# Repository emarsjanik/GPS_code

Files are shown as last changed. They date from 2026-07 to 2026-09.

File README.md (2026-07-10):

# USGS GNSS Reference Station

Autonomous GNSS data logging, RINEX conversion, and GNSS-IR (interferometric reflectometry) processing built around a Unicore UM980 receiver.

For a full, zero-background operator's guide (installation, daily operation, troubleshooting), see [`docs/USER_MANUAL.docx`](docs/USER_MANUAL.docx). This README is the technical quick-reference.

## Data flow

```
UM980 receiver (USB serial)
        │
        ▼
receiver.py            Receiver.record_raw()
        │
        ▼
raw/*.um980             raw binary capture
        │
        ▼
rinex_processor.py      RinexProcessor.convert()  (wraps RTKLIB's convbin)
        │
        ▼
rinex/*.obs, *.nav      RINEX 3.05, with SNR observables
        │
        ▼
gnssrefl_processor.py   GnssIrProcessor.process()  (wraps gnssrefl: rinex2snr → gnssir)
        │
        ▼
products/refl_code/<year>/results/<station>/<doy>.txt   reflector heights
```

`pipeline.py` chains RINEX conversion and GNSS-IR processing for one file. `station_manager.py` chains recording, pipeline processing, and health checks for continuous, unattended operation.

## Requirements

- Ubuntu 20.04 (or compatible)
- Python 3.10+ (`gnssrefl` requires this; the system's default Python on Ubuntu 20.04 is 3.8 and cannot run it — see install notes below)
- [RTKLIB](https://github.com/rtklibexplorer/RTKLIB) (`convbin`), built from source
- [`gnssrefl`](https://github.com/kristinemlarson/gnssrefl) (installs via pip once on Python 3.10+)
- `pyserial`

## Quick start

```bash
git clone https://github.com/emarsjanik/GPS_code.git
cd GPS_code

python3.10 -m venv gnssrefl_venv
source gnssrefl_venv/bin/activate
pip install --upgrade pip
pip install pyserial gnssrefl

# station/resources/station.json needs station_id, lat/lon/height,
# receiver_port, gnssrefl_station_code, and gnssrefl_orbit_source
# (see Configuration below) before anything will work correctly.

python check_layout.py
python -m unittest discover -s tests -v
```

Full, from-scratch installation instructions (including building Python 3.10 and RTKLIB from source, confirmed working on Ubuntu 20.04) are in the user manual, Chapter 10.

## Module map

| Module | Responsibility |
|---|---|
| `config.py` | Loads/validates `station.json`; computes every project path relative to its own file location, not the CWD |
| `receiver.py` | `Receiver` class — all serial I/O with the UM980. Single low-level primitive (`read_message()`) handles both ASCII and binary (NovAtel/Unicore OEM7) framing. `record_raw()` supports chunked recording via `append=True` |
| `database.py` | `Database` class — SQLite persistence, 11 tables, WAL mode, self-upgrading schema |
| `rinex_processor.py` | `RinexProcessor` class — wraps `convbin`. **Requires `-os`** to include SNR observables; without it, output is silently useless for GNSS-IR (no error raised) |
| `gnssrefl_processor.py` | `GnssIrProcessor` class — wraps `gnssrefl` (`rinex2snr` → `gnssir`). See **gnssrefl integration notes** below — several non-obvious, confirmed quirks live here |
| `pipeline.py` | `Pipeline` class — chains RINEX conversion + GNSS-IR processing across whatever's new in `raw/`; archives raw files after successful processing |
| `station_manager.py` | `StationManager` class — top-level orchestrator for continuous operation. Records each UTC day in configurable chunks (default 3600s), runs the pipeline once a day completes, periodic health checks, graceful `SIGTERM`/`SIGINT` handling |
| `station.py` | One-shot dashboard/status check — connects, reports receiver + DB status, exits |
| `exceptions.py`, `version.py` | Shared exception types; version string |
| `start_station.sh`, `stop_station.sh` | Idempotent cron-based wrappers around `station_manager.py` — safe to call repeatedly (no-op if already running), used for autonomous start-on-boot + crash recovery in place of systemd |

All classes follow the same shape: `initialize()` (may raise on a real setup problem) → main working method (never raises for an ordinary operational failure — errors come back as a result object) → `status()` → `shutdown()`.

## gnssrefl integration notes

`gnssrefl_processor.py`'s complexity is almost entirely from confirmed, real quirks in `gnssrefl` 4.1.5 and `convbin`, not incidental design choices:

- **`rinex2snr()` decides RINEX 2.11 vs RINEX 3 purely by the length of the `station` argument** — 4 characters means "assume RINEX 2.11," 9 means "assume RINEX 3." Since `convbin` always outputs RINEX 3 here, `GnssIrProcessor` maintains two station codes: a 4-character one (used by `make_gnssir_input()` and `gnssir()`) and a 9-character one built from it plus a configurable monument number/country code (used only for `rinex2snr()` and the staged filename). Getting this wrong produces no error — just zero usable SNR data.
- **Staged filename convention**: `{STATION9}_R_{YYYY}{DOY}0000_01D_{RATE}S_MO.rnx`, staged under `$REFL_CODE/<year>/rinex/<4-char station>/`. The time segment is always `0000` regardless of the file's real start time.
- **Confirmed upstream bug**: `gnssrefl`'s file-discovery logic checks the current working directory for a same-named file *before* the properly staged directory, and reuses it forever if found — never refreshed. `_stage_rinex_file()` deletes any same-named file from the CWD before staging, specifically to prevent this.
- **Confirmed upstream bug**: `gps.checkEGM()` crashes with `TypeError` the first time `$REFL_CODE/Files` doesn't exist (malformed `subprocess.call()` argument). Worked around by creating that directory proactively in `initialize()`.
- **Reflector height / quality score parsing** is confirmed against a real results file's own header (`% year, doy, RH, sat, UTCtime, ...`): column 3 is RH (meters), column 14 is PkNoise. Reported as the mean across all parseable rows.
- **`soil_moisture`/`snow_depth` are always `None`** — these require separate, later `gnssrefl` modules operating on multi-day history, out of scope for a single day's `gnssir` run.
- Default orbit fetching (multi-GNSS SP3) failed in testing against CDDIS (likely requires an EarthData Login account, and/or same-day rapid products not yet published). Set `"gnssrefl_orbit_source": "nav"` in `station.json` to use broadcast GPS-only ephemeris instead — still requires a small internet download (SOPAC), not fully offline.

## Configuration (`station/resources/station.json`)

| Field | Purpose |
|---|---|
| `station_id`, `latitude`, `longitude`, `height` | Station identity and coordinates |
| `receiver_port`, `receiver_baud`, `receiver_timeout` | Serial connection to the UM980 |
| `rinex_version` | Passed to `convbin`; this project always uses `3.05` |
| `gnssrefl_station_code` | 4-character station code (see integration notes above) |
| `gnssrefl_monument_number`, `gnssrefl_country_code` | Used to build the 9-character RINEX 3 station code |
| `gnssrefl_orbit_source` | `"nav"` for offline-friendly broadcast ephemeris; unset for default multi-GNSS SP3 |
| `gnssrefl_sample_rate` | Recording sample rate in seconds; must match the real `LOG ... ONTIME` interval |
| `record_raw_chunk_seconds` | `StationManager` recording chunk size; 3600 (1h) default, 600 (10min) recommended for cron/systemd-managed deployments so stop/restart stay responsive |
| `manager_retry_delay_seconds`, `health_check_interval_seconds` | `StationManager` tuning |

## Running

```bash
# Autonomous (recommended) — cron-managed, survives crashes and reboots
~/GNSS/v4.1/station/start_station.sh    # idempotent; safe to call repeatedly
~/GNSS/v4.1/station/stop_station.sh     # graceful — waits for the current chunk to finish

# Direct (foreground, blocks)
python3 station_manager.py

# One-shot status check
python3 station.py
```

Crontab (used instead of systemd by choice — see commit history for the reasoning):

```
@reboot /home/argus_user/GNSS/v4.1/station/start_station.sh
*/5 * * * * /home/argus_user/GNSS/v4.1/station/start_station.sh
```

## Testing

```bash
python -m unittest discover -s tests -v
```

163 tests as of this writing, covering every module above with fake `Receiver`/`gnssrefl`/`Pipeline` stand-ins — no real hardware or `gnssrefl` install required to run the suite. All fakes are installed via `sys.modules` injection rather than mocking library internals, so the real integration code paths are exercised, not bypassed.

```bash
python check_layout.py
```

Verifies every expected file is present and non-empty/non-stub — useful after a fresh clone or file transfer.

## Directory outputs

| Path | Contents |
|---|---|
| `raw/` | Raw UM980 binary captures |
| `rinex/` | RINEX `.obs`/`.nav` files |
| `products/refl_code/` | `gnssrefl`'s entire working directory (`$REFL_CODE`) — analysis strategy JSON, staged RINEX, SNR files, results, logs |
| `database/` | `station.db` (SQLite) |
| `logs/` | `database.log`, and (cron setup) `station_manager.pid`/`station_manager.out` |
| `archive/` | Raw files moved here after successful processing |

None of the above are tracked in git (see `.gitignore`) — they're all generated data, along with `gnssrefl_venv/`.

## Hardware

- NUC (Ubuntu 20.04.6 LTS), shared with an unrelated I2R I2RGUS coastal camera system on the same machine
- ArduSimple SimpleRTK3B Budget receiver board (Unicore UM980 chip) — BeiDou/Galileo/GLONASS/GPS/NavIC/QZSS/SBAS
- ArduSimple budget tripleband GNSS antenna — 5 dBi, built-in LNA, IP66

Full specifications: user manual, Chapter 2.

## Known open items

- RINEX/product retention policy in `pipeline.py` is unimplemented — currently nothing prunes `rinex/`, `products/`, or `archive/` over time
- `convbin` build source lives at `~/software/RTKLIB/` on the deployed station (not in this repo) — see user manual Chapter 10 for build steps
- BeiDou/Galileo ephemeris logging works but hasn't been observed within short test windows; needs a longer recording to confirm reliably

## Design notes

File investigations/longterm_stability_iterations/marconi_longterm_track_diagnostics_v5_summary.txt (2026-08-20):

MARCONI LONG-TERM GNSS-R / TIDE TRACK DIAGNOSTICS V5
==============================================================================================================
Primary tide model: EOT20_heightm
Station H_ortho: 18.665 m
Azimuth cluster tolerance: 3.0 deg

GOOD TRACK CRITERIA
--------------------------------------------------------------------------------------------------------------
Minimum observations: 14
Minimum unique days: 14
Minimum tide correlation r: 0.90
Slope range: 0.85 to 1.15
Maximum unit-slope RMS: 30.0 cm
Maximum azimuth SD: 1.00 deg

IMPORTANT
--------------------------------------------------------------------------------------------------------------
The +0.242 m datum offset is diagnostic only.
It is NOT used to select GOOD tracks.
Failure reasons are reported independently for every criterion.

GPS L1 observations matched to tide: 536
Clustered tracks: 28
GOOD tracks: 19

GOOD TRACKS
--------------------------------------------------------------------------------------------------------------
 1. SAT= 29 rise= 1 N= 25 days=25 Az= 113.00±0.04 r=+0.9745 slope=+0.9519 unitRMS=16.49cm
 2. SAT=  9 rise=-1 N= 20 days=20 Az=  35.01±0.01 r=+0.9775 slope=+1.0310 unitRMS=14.85cm
 3. SAT= 25 rise=-1 N= 18 days=18 Az=  47.61±0.02 r=+0.9761 slope=+0.8979 unitRMS=18.53cm
 4. SAT=  9 rise= 1 N= 20 days=20 Az= 124.45±0.05 r=+0.9742 slope=+1.0215 unitRMS=14.03cm
 5. SAT= 29 rise=-1 N= 16 days=16 Az=  33.33±0.02 r=+0.9721 slope=+0.9976 unitRMS=18.52cm
 6. SAT=  4 rise= 1 N= 20 days=20 Az=  96.33±0.02 r=+0.9367 slope=+0.9034 unitRMS=20.66cm
 7. SAT=  8 rise=-1 N= 20 days=20 Az=  83.42±0.15 r=+0.9596 slope=+1.0171 unitRMS=23.95cm
 8. SAT=  4 rise=-1 N= 18 days=18 Az=  30.52±0.01 r=+0.9629 slope=+0.9156 unitRMS=18.89cm
 9. SAT= 27 rise=-1 N= 18 days=18 Az=  63.42±0.01 r=+0.9644 slope=+0.9208 unitRMS=22.00cm
10. SAT= 30 rise= 1 N= 21 days=21 Az= 102.97±0.02 r=+0.9463 slope=+0.9421 unitRMS=20.96cm
11. SAT= 28 rise=-1 N= 18 days=18 Az= 114.26±0.09 r=+0.9561 slope=+0.9674 unitRMS=21.36cm
12. SAT= 20 rise=-1 N= 22 days=22 Az=  69.89±0.11 r=+0.9376 slope=+0.9273 unitRMS=24.02cm
13. SAT=  2 rise=-1 N= 20 days=20 Az=  52.88±0.06 r=+0.9321 slope=+0.9867 unitRMS=26.57cm
14. SAT= 12 rise=-1 N= 23 days=23 Az=  37.54±0.01 r=+0.9583 slope=+0.8733 unitRMS=21.48cm
15. SAT=  6 rise=-1 N= 21 days=21 Az= 114.72±0.14 r=+0.9345 slope=+0.9793 unitRMS=23.69cm
16. SAT= 21 rise=-1 N= 21 days=21 Az=  92.86±0.18 r=+0.9089 slope=+0.9246 unitRMS=26.55cm
17. SAT=  5 rise=-1 N= 19 days=19 Az= 117.30±0.21 r=+0.9419 slope=+0.8847 unitRMS=23.18cm
18. SAT= 16 rise=-1 N= 18 days=18 Az=  96.47±0.08 r=+0.9310 slope=+0.8633 unitRMS=27.23cm
19. SAT= 30 rise=-1 N= 19 days=19 Az=  33.75±0.01 r=+0.9217 slope=+0.9210 unitRMS=26.03cm

ALL TRACKS — RANKED BY LONG-TERM SCORE
--------------------------------------------------------------------------------------------------------------
 1. SAT= 29 rise= 1 N= 25 days=25 Az= 113.00±0.04 r=+0.9745 slope=+0.9519 unitRMS=16.49cm FAIL=PASS score=0.824
 2. SAT=  9 rise=-1 N= 20 days=20 Az=  35.01±0.01 r=+0.9775 slope=+1.0310 unitRMS=14.85cm FAIL=PASS score=0.811
 3. SAT= 25 rise=-1 N= 18 days=18 Az=  47.61±0.02 r=+0.9761 slope=+0.8979 unitRMS=18.53cm FAIL=PASS score=0.800
 4. SAT=  9 rise= 1 N= 20 days=20 Az= 124.45±0.05 r=+0.9742 slope=+1.0215 unitRMS=14.03cm FAIL=PASS score=0.798
 5. SAT= 29 rise=-1 N= 16 days=16 Az=  33.33±0.02 r=+0.9721 slope=+0.9976 unitRMS=18.52cm FAIL=PASS score=0.788
 6. SAT=  4 rise= 1 N= 20 days=20 Az=  96.33±0.02 r=+0.9367 slope=+0.9034 unitRMS=20.66cm FAIL=PASS score=0.786
 7. SAT=  8 rise=-1 N= 20 days=20 Az=  83.42±0.15 r=+0.9596 slope=+1.0171 unitRMS=23.95cm FAIL=PASS score=0.781
 8. SAT=  4 rise=-1 N= 18 days=18 Az=  30.52±0.01 r=+0.9629 slope=+0.9156 unitRMS=18.89cm FAIL=PASS score=0.781
 9. SAT= 27 rise=-1 N= 18 days=18 Az=  63.42±0.01 r=+0.9644 slope=+0.9208 unitRMS=22.00cm FAIL=PASS score=0.780
10. SAT= 30 rise= 1 N= 21 days=21 Az= 102.97±0.02 r=+0.9463 slope=+0.9421 unitRMS=20.96cm FAIL=PASS score=0.770
11. SAT= 28 rise=-1 N= 18 days=18 Az= 114.26±0.09 r=+0.9561 slope=+0.9674 unitRMS=21.36cm FAIL=PASS score=0.768
12. SAT= 20 rise=-1 N= 22 days=22 Az=  69.89±0.11 r=+0.9376 slope=+0.9273 unitRMS=24.02cm FAIL=PASS score=0.767
13. SAT=  2 rise=-1 N= 20 days=20 Az=  52.88±0.06 r=+0.9321 slope=+0.9867 unitRMS=26.57cm FAIL=PASS score=0.761
14. SAT= 12 rise=-1 N= 23 days=23 Az=  37.54±0.01 r=+0.9583 slope=+0.8733 unitRMS=21.48cm FAIL=PASS score=0.754
15. SAT= 13 rise=-1 N= 13 days=13 Az=  38.84±0.07 r=+0.9684 slope=+0.8717 unitRMS=19.15cm FAIL=N,DAYS score=0.750
16. SAT=  6 rise=-1 N= 21 days=21 Az= 114.72±0.14 r=+0.9345 slope=+0.9793 unitRMS=23.69cm FAIL=PASS score=0.744
17. SAT=  1 rise=-1 N= 20 days=20 Az=  56.25±0.08 r=+0.8903 slope=+0.9349 unitRMS=29.04cm FAIL=R score=0.742
18. SAT= 21 rise=-1 N= 21 days=21 Az=  92.86±0.18 r=+0.9089 slope=+0.9246 unitRMS=26.55cm FAIL=PASS score=0.738
19. SAT=  5 rise=-1 N= 19 days=19 Az= 117.30±0.21 r=+0.9419 slope=+0.8847 unitRMS=23.18cm FAIL=PASS score=0.733
20. SAT= 26 rise=-1 N= 17 days=17 Az=  90.74±0.20 r=+0.8957 slope=+0.9088 unitRMS=29.37cm FAIL=R score=0.724
21. SAT= 16 rise=-1 N= 18 days=18 Az=  96.47±0.08 r=+0.9310 slope=+0.8633 unitRMS=27.23cm FAIL=PASS score=0.723
22. SAT= 15 rise=-1 N= 24 days=24 Az=  93.24±0.19 r=+0.8934 slope=+0.8980 unitRMS=30.68cm FAIL=R,RMS score=0.721
23. SAT= 24 rise=-1 N= 25 days=25 Az=  57.25±0.06 r=+0.9267 slope=+0.8372 unitRMS=25.05cm FAIL=SLOPE score=0.708
24. SAT= 30 rise=-1 N= 19 days=19 Az=  33.75±0.01 r=+0.9217 slope=+0.9210 unitRMS=26.03cm FAIL=PASS score=0.703
25. SAT= 12 rise= 1 N=  5 days= 5 Az= 133.23±0.06 r=+0.9777 slope=+0.6363 unitRMS=8.48cm FAIL=N,DAYS,SLOPE score=0.696
26. SAT=  3 rise=-1 N= 19 days=19 Az=  37.17±0.05 r=+0.9231 slope=+0.8107 unitRMS=23.24cm FAIL=SLOPE score=0.692
27. SAT= 31 rise=-1 N= 11 days=11 Az= 127.07±0.08 r=+0.9334 slope=+1.0884 unitRMS=21.15cm FAIL=N,DAYS score=0.670
28. SAT= 19 rise=-1 N= 14 days=14 Az= 148.96±0.13 r=+0.1945 slope=+0.0154 unitRMS=66.00cm FAIL=R,SLOPE,RMS score=0.231

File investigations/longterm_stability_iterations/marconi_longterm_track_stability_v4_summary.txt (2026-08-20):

MARCONI LONG-TERM GNSS-R / TIDE PIPELINE V4
============================================================================================

GNSS-IR configuration: ocean17_23_l1_e5_13
Primary tide model: EOT20_heightm
Diagnostic offset: +0.242 m

GOOD-track criteria:
  observations >= 14
  unique days   >= 14
  tide r        >= 0.9
  slope         = 0.85 to 1.15
  unit RMS      <= 30.0 cm
  azimuth SD    <= 1.0 deg
  +24.2 cm is NOT used to select good tracks.

Total clustered tracks: 34
GOOD tracks: 0

GOOD-TRACK POPULATION STATISTICS
--------------------------------------------------------------------------------------------
Mean bias                                   nan cm                  nan cm
Mean absolute deviation                     nan cm                  nan cm
Median absolute deviation                   nan cm                  nan cm
RMS                                         nan cm                  nan cm

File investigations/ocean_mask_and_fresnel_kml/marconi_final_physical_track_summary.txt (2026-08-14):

MARCONI FINAL PHYSICAL GNSS-R TRACK SCREEN
================================================================================================

Topobathy: 2021022FA_Marconi_topobathy_1m.tif
Primary tide: EOT20_heightm
H_ortho: 18.665 m
Datum transformation: +0.242 m

STATISTICAL SCREEN:
  N >= 10
  |median bias| <= 0.050 m
  RMS <= 0.200 m
  r >= 0.93

PHYSICAL SCREEN:
  adequate raster coverage >= 0.90
  9° water-dominant >= 0.80
  A-class 13° water >= 0.50

Statistically selected tracks: 4
Physically accepted A/B tracks: 2
Final observations: 29
Daily product days: 20

TRACK CLASSIFICATION
------------------------------------------------------------------------------------------------
PRN 29 RISING  Az= 113.01 N=23 r=+0.9765 RMS=16.5 cm bias=-3.2 cm C5=0.000 C9=0.450 C13=1.000 W5=nan W9=1.000 W13=0.350 C_INSUFFICIENT_RASTER_COVERAGE
PRN 13 SETTING Az=  38.84 N=12 r=+0.9719 RMS=19.5 cm bias=+4.0 cm C5=1.000 C9=1.000 C13=0.998 W5=1.000 W9=0.933 W13=0.058 B_WATER_DOMINANT_LOW_ANGLE
PRN  4 RISING  Az=  96.33 N=17 r=+0.9459 RMS=19.7 cm bias=+0.2 cm C5=0.668 C9=1.000 C13=1.000 W5=1.000 W9=1.000 W13=0.702 B_WATER_DOMINANT_LOW_ANGLE
PRN  9 RISING  Az= 124.46 N=17 r=+0.9759 RMS=13.7 cm bias=+2.1 cm C5=0.000 C9=0.000 C13=0.456 W5=nan W9=nan W13=0.000 C_INSUFFICIENT_RASTER_COVERAGE

FINAL WATER-LEVEL PRODUCT STATUS
------------------------------------------------------------------------------------------------
Only A/B tracks are included in the final combined product.
C tracks require a larger topobathy raster.
D/E tracks are not physically accepted under the current rules.

FINAL TRACKS:
  PRN 13 S Az=38.8° class=B_WATER_DOMINANT_LOW_ANGLE
  PRN 4 R Az=96.3° class=B_WATER_DOMINANT_LOW_ANGLE

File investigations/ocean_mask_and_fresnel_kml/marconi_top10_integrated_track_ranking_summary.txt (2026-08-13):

MARCONI TOP-10 INTEGRATED GNSS-R / FRESNEL / TOPOBATHY TEST
====================================================================================================
Top N: 10
Minimum repeated-track N: 3
Geometry elevations: [5.0, 9.0, 13.0]
DATUM_SHIFT_M: +0.00 m

CLASSIFICATION
A = strong ocean candidate: N>=4, |r|>=0.99,
    slope 0.85-1.15, unit RMS<=10 cm, wet13>=70%
B = probable ocean / mixed shoreline
C = tide-responsive but geometry not confirmed
D = weak or non-tidal

FINAL RANKING
----------------------------------------------------------------------------------------------------
 1. SAT= 26 N= 4 Az=90.93 r=+0.9966 slope=+0.9400 RMS=4.18cm wet13=0.750 class=A_STRONG_OCEAN_CANDIDATE score=0.861
 2. SAT=  1 N= 4 Az=56.33 r=+0.9817 slope=+0.7963 RMS=10.63cm wet13=0.793 class=B_PROBABLE_OCEAN_OR_MIXED_SHORELINE score=0.826
 3. SAT= 21 N= 4 Az=92.93 r=+0.9973 slope=+1.2293 RMS=7.31cm wet13=0.717 class=B_PROBABLE_OCEAN_OR_MIXED_SHORELINE score=0.811
 4. SAT= 24 N= 4 Az=57.28 r=+0.9591 slope=+0.6829 RMS=13.84cm wet13=0.797 class=C_TIDE_RESPONSIVE_GEOMETRY_UNCONFIRMED score=0.781
 5. SAT= 16 N= 4 Az=96.40 r=+0.9952 slope=+1.4264 RMS=11.48cm wet13=0.602 class=C_TIDE_RESPONSIVE_GEOMETRY_UNCONFIRMED score=0.765
 6. SAT=  2 N= 4 Az=52.82 r=+0.9633 slope=+0.6438 RMS=15.31cm wet13=0.664 class=C_TIDE_RESPONSIVE_GEOMETRY_UNCONFIRMED score=0.754
 7. SAT= 12 N= 3 Az=37.54 r=+0.9929 slope=+0.9896 RMS=4.45cm wet13=0.274 class=C_TIDE_RESPONSIVE_GEOMETRY_UNCONFIRMED score=0.690
 8. SAT= 28 N= 4 Az=114.33 r=+0.9733 slope=+0.7675 RMS=12.40cm wet13=0.410 class=C_TIDE_RESPONSIVE_GEOMETRY_UNCONFIRMED score=0.638
 9. SAT=  6 N= 3 Az=114.61 r=+0.9186 slope=+0.5661 RMS=12.52cm wet13=0.339 class=C_TIDE_RESPONSIVE_GEOMETRY_UNCONFIRMED score=0.598
10. SAT=  3 N= 3 Az=37.12 r=+0.9763 slope=+0.8086 RMS=6.95cm wet13=0.109 class=C_TIDE_RESPONSIVE_GEOMETRY_UNCONFIRMED score=0.595

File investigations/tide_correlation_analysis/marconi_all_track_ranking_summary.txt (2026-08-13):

MARCONI ALL-TRACK GNSS-R CANDIDATE RANKING
====================================================================================================
Only repeated satellite/frequency tracks with N >= 3 are ranked.
Ranking uses tide response, slope closeness, quality, azimuth
repeatability, fixed-slope residual, and optional 13-degree
topobathy wet fraction.

TOP 25 TRACKS
----------------------------------------------------------------------------------------------------
 1. SAT= 26 FREQ=  1 N= 4 Az= 90.93±0.04 RH=19.002±0.400 r=+0.9966 slope=+0.9400 PkN=3.62 Amp=45.8 wet13=0.750 RMS=4.18cm score=0.838
 2. SAT= 21 FREQ=  1 N= 4 Az= 92.93±0.04 RH=19.127±0.366 r=+0.9973 slope=+1.2293 PkN=3.68 Amp=42.5 wet13=0.717 RMS=7.31cm score=0.789
 3. SAT= 12 FREQ=  1 N= 3 Az= 37.54±0.00 RH=18.604±0.374 r=+0.9929 slope=+0.9896 PkN=3.20 Amp=33.0 wet13=nan RMS=4.45cm score=0.778
 4. SAT=  1 FREQ=  1 N= 4 Az= 56.33±0.01 RH=19.341±0.337 r=+0.9817 slope=+0.7963 PkN=3.71 Amp=51.7 wet13=nan RMS=10.63cm score=0.743
 5. SAT= 16 FREQ=  1 N= 4 Az= 96.40±0.01 RH=19.398±0.366 r=+0.9952 slope=+1.4264 PkN=4.00 Amp=46.7 wet13=0.602 RMS=11.48cm score=0.736
 6. SAT=  3 FREQ=  1 N= 3 Az= 37.12±0.01 RH=18.957±0.220 r=+0.9763 slope=+0.8086 PkN=3.13 Amp=32.0 wet13=nan RMS=6.95cm score=0.719
 7. SAT= 24 FREQ=  1 N= 4 Az= 57.28±0.01 RH=19.258±0.262 r=+0.9591 slope=+0.6829 PkN=3.79 Amp=40.7 wet13=nan RMS=13.84cm score=0.704
 8. SAT=  2 FREQ=  1 N= 4 Az= 52.82±0.02 RH=19.562±0.256 r=+0.9633 slope=+0.6438 PkN=3.85 Amp=58.6 wet13=nan RMS=15.31cm score=0.695
 9. SAT= 28 FREQ=  1 N= 4 Az=114.33±0.02 RH=18.412±0.332 r=+0.9733 slope=+0.7675 PkN=3.23 Amp=29.7 wet13=nan RMS=12.40cm score=0.689
10. SAT=  6 FREQ=  1 N= 3 Az=114.61±0.02 RH=18.650±0.155 r=+0.9186 slope=+0.5661 PkN=3.39 Amp=32.9 wet13=nan RMS=12.52cm score=0.645
11. SAT=  9 FREQ=  1 N= 8 Az= 79.70±44.70 RH=18.656±0.382 r=+0.9549 slope=+1.0797 PkN=3.08 Amp=30.2 wet13=nan RMS=11.65cm score=0.608
12. SAT= 27 FREQ=  1 N= 4 Az= 63.41±0.01 RH=19.610±0.246 r=+0.9213 slope=+1.9742 PkN=4.15 Amp=67.6 wet13=nan RMS=14.71cm score=0.584
13. SAT= 29 FREQ=  1 N= 6 Az= 86.42±37.56 RH=18.460±0.302 r=+0.9332 slope=+0.7828 PkN=3.23 Amp=32.2 wet13=nan RMS=13.38cm score=0.577
14. SAT=  8 FREQ=  1 N= 4 Az= 83.28±0.01 RH=19.738±0.168 r=+0.6696 slope=+0.4281 PkN=4.06 Amp=56.9 wet13=nan RMS=19.50cm score=0.558
15. SAT=  4 FREQ=  1 N= 6 Az= 74.39±31.02 RH=18.696±0.273 r=+0.9088 slope=+0.6661 PkN=3.60 Amp=34.9 wet13=nan RMS=16.85cm score=0.557
16. SAT= 25 FREQ=  1 N= 3 Az= 84.38±51.96 RH=18.312±0.278 r=+0.9917 slope=+0.4082 PkN=3.07 Amp=23.4 wet13=nan RMS=40.12cm score=0.474
17. SAT= 30 FREQ=  1 N= 6 Az= 68.36±34.60 RH=19.103±0.281 r=+0.8438 slope=+0.5561 PkN=3.25 Amp=36.5 wet13=nan RMS=24.19cm score=0.473
18. SAT=  5 FREQ=  1 N= 4 Az=117.24±0.04 RH=19.452±0.260 r=+0.7690 slope=+2.5749 PkN=3.61 Amp=44.5 wet13=nan RMS=20.61cm score=0.465
19. SAT= 15 FREQ=  1 N= 4 Az= 93.14±0.02 RH=19.495±0.091 r=+0.3139 slope=+0.1075 PkN=3.81 Amp=50.7 wet13=nan RMS=25.19cm score=0.366
20. SAT= 20 FREQ=  1 N= 4 Az= 69.92±0.01 RH=19.541±0.175 r=+0.0151 slope=+0.0345 PkN=4.12 Amp=51.4 wet13=nan RMS=19.05cm score=0.290

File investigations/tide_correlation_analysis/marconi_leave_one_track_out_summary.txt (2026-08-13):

MARCONI LEAVE-ONE-TRACK-OUT CROSS-VALIDATION
====================================================================================================
Calibration is estimated from two tracks and applied unchanged
to the held-out third track.

HOLD PRN26_AZ91                     EOT20_heightm      C=-0.0900 m r=+0.9969 slope=+0.9883 RMS=6.63 cm MAE=5.81 cm
HOLD PRN26_AZ91                     GOT5.5_heightm     C=-0.1058 m r=+0.9971 slope=+0.9044 RMS=6.53 cm MAE=6.20 cm
HOLD PRN26_AZ91                     GOT5.6_heightm     C=-0.0929 m r=+0.9960 slope=+0.9433 RMS=8.24 cm MAE=7.03 cm
HOLD PRN26_AZ91                     FES2022_heightm    C=-0.0895 m r=+0.9961 slope=+0.9280 RMS=8.14 cm MAE=6.96 cm
HOLD PRN26_AZ91                     TIDE_ENSEMBLE_m    C=-0.0946 m r=+0.9966 slope=+0.9400 RMS=7.20 cm MAE=6.11 cm
HOLD PRN21_AZ93                     EOT20_heightm      C=-0.0605 m r=+0.9971 slope=+1.3117 RMS=9.60 cm MAE=8.31 cm
HOLD PRN21_AZ93                     GOT5.5_heightm     C=-0.0722 m r=+0.9984 slope=+1.1266 RMS=7.64 cm MAE=6.11 cm
HOLD PRN21_AZ93                     GOT5.6_heightm     C=-0.0537 m r=+0.9965 slope=+1.2583 RMS=9.36 cm MAE=7.20 cm
HOLD PRN21_AZ93                     FES2022_heightm    C=-0.0508 m r=+0.9967 slope=+1.2350 RMS=9.02 cm MAE=6.69 cm
HOLD PRN21_AZ93                     TIDE_ENSEMBLE_m    C=-0.0593 m r=+0.9973 slope=+1.2293 RMS=8.70 cm MAE=6.56 cm
HOLD PRN16_AZ96                     EOT20_heightm      C=-0.0615 m r=+0.9965 slope=+1.5219 RMS=13.18 cm MAE=10.93 cm
HOLD PRN16_AZ96                     GOT5.5_heightm     C=-0.0997 m r=+0.9962 slope=+1.3261 RMS=9.76 cm MAE=7.61 cm
HOLD PRN16_AZ96                     GOT5.6_heightm     C=-0.0619 m r=+0.9936 slope=+1.4519 RMS=12.28 cm MAE=9.70 cm
HOLD PRN16_AZ96                     FES2022_heightm    C=-0.0617 m r=+0.9938 slope=+1.4181 RMS=11.61 cm MAE=9.16 cm
HOLD PRN16_AZ96                     TIDE_ENSEMBLE_m    C=-0.0712 m r=+0.9952 slope=+1.4264 RMS=11.54 cm MAE=9.17 cm

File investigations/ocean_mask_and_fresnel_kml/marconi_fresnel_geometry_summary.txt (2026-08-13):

================================================================================
MARCONI FRESNEL / WATER-SIDE GEOMETRY CLASSIFICATION
================================================================================

Input records: 82
Water bearing: 83.060 deg
Reference shoreline distance: 71.780 m
NOTE: this is a reference shoreline plane, not a digitized shoreline polygon.

OVERALL CLASSIFICATION
  OPEN_WATER_CANDIDATE: 0
  MIXED_LAND_WATER: 0
  LAND_LIKELY: 57
  INVALID: 25

BY FREQUENCY
  freq=1: 17
  freq=5: 4
  freq=20: 3
  freq=101: 23
  freq=102: 2
  freq=201: 12
  freq=205: 6
  freq=207: 5
  freq=302: 10

REPEATED SAT/FREQ TRACKS
  sat=1 freq=1 n=4
  sat=9 freq=1 n=2
  sat=14 freq=1 n=3
  sat=23 freq=1 n=2
  sat=25 freq=5 n=2
  sat=29 freq=1 n=4
  sat=102 freq=101 n=2
  sat=103 freq=101 n=3
  sat=109 freq=101 n=2
  sat=115 freq=101 n=3
  sat=116 freq=101 n=2
  sat=121 freq=101 n=2
  sat=218 freq=207 n=2
  sat=236 freq=201 n=2

INTERPRETATION
OPEN_WATER_CANDIDATE means at least one sampled elevation (5, 10, or 15 deg) has >=80% of the Fresnel-zone polygon on the water side of the reference shoreline plane.
MIXED_LAND_WATER means the footprint intersects both sides at one or more sampled elevations.
LAND_LIKELY means all sampled elevations have <=20% of the footprint on the water side.
These classifications are diagnostic only. A real shoreline polygon should replace the reference plane before production masking is changed.

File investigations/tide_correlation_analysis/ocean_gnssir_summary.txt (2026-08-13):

================================================================================
CONTROLLED MARCONI OCEAN GNSS-IR PRODUCT
================================================================================

INPUTS
CSV: gnssir_tide_arc_analysis.csv
Tide workbook: marconi_tides_sherwood.xlsx

PRIMARY FILTERS
Frequency: 1
Ocean azimuth: 35.0 to 135.0 deg
PkNoise >= 2.80
Amp >= 5.00
Arc duration <= 40.0 min
Elevation window: 5.0-15.0 deg
Orthometric/reference height: 18.665 m

COUNTS
Input usable records: 82
Included records: 8
Excluded records: 74

INCLUSION BY SAT/FREQ
  sat=  9 freq=  1: 2
  sat= 12 freq=  1: 1
  sat= 29 freq=  1: 4
  sat= 31 freq=  1: 1

EXCLUSION REASONS
  not_primary_frequency: 65
  outside_ocean_azimuth: 9

MODEL COMPARISON: RAW WATER-LEVEL ANOMALY
(absolute datum is not assumed; constant offset is removed)

EOT20: n=8 r=-0.4834 offset=+0.0118 m bias_removed_RMS=79.63 cm slope=-0.4584 fit_RMS=39.39 cm
GOT5.5: n=8 r=-0.5019 offset=+0.0326 m bias_removed_RMS=82.64 cm slope=-0.4489 fit_RMS=38.92 cm
GOT5.6: n=8 r=-0.4586 offset=+0.0087 m bias_removed_RMS=80.60 cm slope=-0.4183 fit_RMS=39.99 cm
FES2022: n=8 r=-0.4608 offset=+0.0109 m bias_removed_RMS=81.06 cm slope=-0.4164 fit_RMS=39.94 cm

IMPORTANT
This product does NOT use gnssrefl subdaily as its primary water-level estimator. Each individual GNSS-IR arc remains auditable. No spline is used in the primary product.
Water-level convention is H_ortho - RH. Absolute comparison to the tide datum requires independent vertical-datum validation. The anomaly comparison is the preferred first diagnostic.

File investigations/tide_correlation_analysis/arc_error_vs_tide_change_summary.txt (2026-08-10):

USGS GNSS-IR ARC ERROR VS WITHIN-ARC TIDAL CHANGE
============================================================
Station: usgs
Year: 2026
DOY: 204-207
Usable arcs: 99
Total extracted: 811
QC passing: 99
Outside model range: 0

TIME CONVENTION WARNING
GNSS-IR timestamps are treated as UTC. Tide-model Excel timestamps are timezone-naive. This script assumes the same clock basis; that assumption is not independently proven.

GLOBAL SHAPE FIT
scale=-0.037521617
offset_m=-1.563744701
correlation=-0.069077990
shape_rms_cm=27.017059
shape_mae_cm=20.630193

PRIMARY CORRELATIONS
pearson_abs_error_vs_abs_tide_change=0.057428606
spearman_abs_error_vs_abs_tide_change=0.133725011
pearson_abs_error_vs_duration=0.084777800
spearman_abs_error_vs_duration=0.197525979
pearson_abs_error_vs_abs_tide_rate=0.028340782

TIDAL-MOVEMENT BINS
0-2 cm: n=5, mean_abs_error_cm=24.455153, median_abs_error_cm=15.105285, rms_error_cm=30.136183
2-5 cm: n=8, mean_abs_error_cm=13.081570, median_abs_error_cm=11.473216, rms_error_cm=14.816120
5-10 cm: n=13, mean_abs_error_cm=24.425935, median_abs_error_cm=20.243074, rms_error_cm=34.094362
10-20 cm: n=59, mean_abs_error_cm=19.726557, median_abs_error_cm=16.881842, rms_error_cm=26.448530
>20 cm: n=14, mean_abs_error_cm=23.861198, median_abs_error_cm=25.066802, rms_error_cm=26.161107

FREQUENCY SUMMARY
freq=1: n=38, mean_abs_error_cm=19.549836, rms_error_cm=26.141585
freq=5: n=4, mean_abs_error_cm=21.911606, rms_error_cm=24.405569
freq=20: n=1, mean_abs_error_cm=1.962977, rms_error_cm=1.962977
freq=101: n=20, mean_abs_error_cm=25.729053, rms_error_cm=34.457492
freq=102: n=2, mean_abs_error_cm=23.246969, rms_error_cm=26.924409
freq=201: n=13, mean_abs_error_cm=16.441170, rms_error_cm=18.576281
freq=205: n=3, mean_abs_error_cm=19.259913, rms_error_cm=21.705119
freq=207: n=5, mean_abs_error_cm=37.838969, rms_error_cm=43.443139
freq=302: n=13, mean_abs_error_cm=14.469322, rms_error_cm=16.113079

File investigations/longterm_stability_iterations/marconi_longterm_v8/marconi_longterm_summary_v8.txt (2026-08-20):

MARCONI LONG-TERM GNSS-R / TIDE PIPELINE V8
====================================================================================================

Base directory: /home/argus_user/GNSS/v4.1
REFL_CODE: /home/argus_user/GNSS/v4.1/products/refl_code
Result directory: /home/argus_user/GNSS/v4.1/products/refl_code/2026/results/usgs/ocean17_23_l1_e5_13
GNSS reference height: 18.665 m
Diagnostic offset: +0.242 m

GOOD-track criteria:
  observations >= 14
  unique days   >= 14
  tide r        >= 0.9
  slope         = 0.85 to 1.15
  unit RMS      <= 30.0 cm
  azimuth SD    <= 1.0 deg
  +24.2 cm is NOT used to select good tracks.

GNSS-R transformation:
  GNSS-R water elevation = 18.665 m - RH

Total GNSS-R observations loaded: 536
GOOD tracks: 6
GOOD observations: 115

RAW
---
  observations             = 115
  mean bias                = -20.111 cm
  mean absolute deviation = 21.755 cm
  median absolute deviation = 17.811 cm
  RMS                      = 27.215 cm

GNSS-R +0.242 m
---------------
  observations             = 115
  mean bias                = 4.089 cm
  mean absolute deviation = 15.772 cm
  median absolute deviation = 12.896 cm
  RMS                      = 18.786 cm

TRACKS
====================================================================================================
 1 SAT=12 rise= 1 N=  5 days=  5 Az= 133.23+/-0.02 r=+0.9777 slope=+0.6363 rawRMS=31.73cm BAD
 2 SAT= 9 rise=-1 N= 20 days= 20 Az=  35.01+/-0.01 r=+0.9775 slope=+1.0310 rawRMS=27.01cm GOOD
 3 SAT=25 rise=-1 N= 18 days= 18 Az=  47.61+/-0.01 r=+0.9761 slope=+0.8979 rawRMS=26.57cm GOOD
 4 SAT=29 rise= 1 N= 25 days= 25 Az= 113.00+/-0.02 r=+0.9745 slope=+0.9519 rawRMS=32.24cm NEAR-GOOD
 5 SAT= 9 rise= 1 N= 20 days= 20 Az= 124.45+/-0.03 r=+0.9742 slope=+1.0215 rawRMS=28.65cm GOOD
 6 SAT=29 rise=-1 N= 16 days= 16 Az=  33.33+/-0.01 r=+0.9721 slope=+0.9976 rawRMS=26.63cm GOOD
 7 SAT=13 rise=-1 N= 13 days= 13 Az=  38.84+/-0.03 r=+0.9684 slope=+0.8717 rawRMS=24.58cm BAD
 8 SAT=27 rise=-1 N= 18 days= 18 Az=  63.42+/-0.01 r=+0.9644 slope=+0.9208 rawRMS=36.10cm NEAR-GOOD
 9 SAT= 4 rise=-1 N= 18 days= 18 Az=  30.52+/-0.01 r=+0.9629 slope=+0.9156 rawRMS=28.98cm GOOD
10 SAT= 8 rise=-1 N= 20 days= 20 Az=  83.42+/-0.09 r=+0.9596 slope=+1.0171 rawRMS=37.31cm NEAR-GOOD
11 SAT=12 rise=-1 N= 23 days= 23 Az=  37.54+/-0.01 r=+0.9583 slope=+0.8733 rawRMS=25.53cm GOOD
12 SAT=28 rise=-1 N= 18 days= 18 Az= 114.25+/-0.05 r=+0.9561 slope=+0.9674 rawRMS=30.89cm NEAR-GOOD
13 SAT=30 rise= 1 N= 21 days= 21 Az= 102.97+/-0.01 r=+0.9463 slope=+0.9421 rawRMS=32.21cm NEAR-GOOD
14 SAT= 5 rise=-1 N= 19 days= 19 Az= 117.30+/-0.10 r=+0.9419 slope=+0.8847 rawRMS=37.98cm NEAR-GOOD
15 SAT=20 rise=-1 N= 22 days= 22 Az=  69.89+/-0.06 r=+0.9376 slope=+0.9273 rawRMS=41.05cm NEAR-GOOD
16 SAT= 4 rise= 1 N= 20 days= 20 Az=  96.33+/-0.01 r=+0.9367 slope=+0.9034 rawRMS=34.08cm NEAR-GOOD
17 SAT= 6 rise=-1 N= 21 days= 21 Az= 114.72+/-0.07 r=+0.9345 slope=+0.9793 rawRMS=39.50cm NEAR-GOOD
18 SAT=31 rise=-1 N= 11 days= 11 Az= 127.07+/-0.05 r=+0.9334 slope=+1.0884 rawRMS=37.88cm BAD
19 SAT= 2 rise=-1 N= 20 days= 20 Az=  52.88+/-0.03 r=+0.9321 slope=+0.9867 rawRMS=35.30cm NEAR-GOOD
20 SAT=16 rise=-1 N= 18 days= 18 Az=  96.47+/-0.04 r=+0.9310 slope=+0.8633 rawRMS=40.09cm NEAR-GOOD
21 SAT=24 rise=-1 N= 25 days= 25 Az=  57.25+/-0.03 r=+0.9267 slope=+0.8372 rawRMS=33.39cm NEAR-GOOD
22 SAT= 3 rise=-1 N= 19 days= 19 Az=  37.17+/-0.03 r=+0.9231 slope=+0.8107 rawRMS=27.71cm NEAR-GOOD
23 SAT=30 rise=-1 N= 19 days= 19 Az=  33.75+/-0.01 r=+0.9217 slope=+0.9210 rawRMS=41.63cm NEAR-GOOD
24 SAT=21 rise=-1 N= 21 days= 21 Az=  92.86+/-0.09 r=+0.9089 slope=+0.9246 rawRMS=44.78cm NEAR-GOOD
25 SAT=26 rise=-1 N= 17 days= 17 Az=  90.74+/-0.10 r=+0.8957 slope=+0.9088 rawRMS=40.62cm NEAR-GOOD
26 SAT=15 rise=-1 N= 24 days= 24 Az=  93.24+/-0.10 r=+0.8934 slope=+0.8980 rawRMS=40.53cm NEAR-GOOD
27 SAT= 1 rise=-1 N= 20 days= 20 Az=  56.25+/-0.04 r=+0.8903 slope=+0.9349 rawRMS=36.00cm NEAR-GOOD
28 SAT=25 rise= 1 N=  3 days=  3 Az= 157.85+/-0.01 r=+0.3233 slope=+0.0512 rawRMS=35.26cm BAD
29 SAT=19 rise=-1 N= 14 days= 14 Az= 148.96+/-0.09 r=+0.1945 slope=+0.0154 rawRMS=138.86cm BAD
30 SAT=13 rise= 1 N=  3 days=  3 Az= 137.09+/-0.02 r=-0.2169 slope=-0.1160 rawRMS=38.29cm BAD
31 SAT= 3 rise= 1 N=  2 days=  2 Az= 137.78+/-0.00 r=-1.0000 slope=-1.3866 rawRMS=17.91cm BAD
32 SAT=11 rise=-1 N=  1 days=  1 Az= 133.44+/-0.00 r=+nan slope=+nan rawRMS=15.85cm BAD
33 SAT=17 rise=-1 N=  1 days=  1 Az= 137.18+/-0.00 r=+nan slope=+nan rawRMS=70.37cm BAD
34 SAT=32 rise=-1 N=  1 days=  1 Az= 147.73+/-0.00 r=+nan slope=+nan rawRMS=171.81cm BAD

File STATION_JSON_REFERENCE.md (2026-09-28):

# station.json Reference

This document explains every setting in `station/resources/station.json`.

You don't need to read this top to bottom to get started — `./setup_station.sh`
walks you through every field interactively with the same explanations shown
here, and sensible defaults for most of it. This document exists for when you
want to understand what a setting actually does, change something later by
hand, or double-check a value before a long unattended recording run.

Settings are grouped the same way the setup wizard presents them. Fields
marked **Required** have no safe default — the station will not run
correctly without a real value. Fields marked **Optional** are genuinely
optional: if you leave them out of the file entirely, gnssrefl's own
internal default is used, unchanged.

---

## Station identity

| Field | Type | Required? | Description |
|---|---|---|---|
| `station_id` | string | Required | A short identifier for your station, e.g. `"USGS001"`. Used in reports, RINEX file headers, and (if `gnssrefl_station_code` below isn't set) to derive the 4-character code gnssrefl itself uses internally. |
| `station_name` | string | Recommended | A human-readable name, e.g. `"Marconi Beach"`. Shown on dashboards and in reports; has no effect on processing. |
| `agency` | string | Recommended | Your organization, e.g. `"USGS"`. Written into RINEX file headers. |
| `observer` | string | Recommended | Who's responsible for the station, e.g. `"Jane Smith"`. Written into RINEX file headers. |

## Receiver

| Field | Type | Required? | Description |
|---|---|---|---|
| `receiver_model` | string | Recommended | Your receiver's model, e.g. `"Unicore UM980"`. Written into RINEX file headers and shown on the dashboard. |
| `receiver_firmware` | string | Optional | Firmware version. Usually left blank — the station reads this from the receiver itself and records it automatically the first time it connects. |
| `receiver_port` | string | Required | The serial device path the receiver is connected to, e.g. `"/dev/USB_GPS"` (a stable, named symlink is strongly recommended over `/dev/ttyUSB0`, which can change across reboots). |
| `receiver_baud` | integer | Required | Serial baud rate. `115200` is correct for the UM980 at its default configuration. |
| `receiver_timeout` | number | Required | Seconds to wait for a response to a query before giving up. `2.0` is a reasonable default. |

## Location — **the most important section**

Everything GNSS-IR computes depends on knowing exactly where your antenna
is. Getting this wrong doesn't cause an error — it silently produces
confident-looking, meaningless results.

| Field | Type | Required? | Description |
|---|---|---|---|
| `latitude` | number | **Required, must be accurate** | Decimal degrees, e.g. `41.8928243333`. **Not** degrees/minutes/seconds — if your survey data is in DMS format, convert it first. |
| `longitude` | number | **Required, must be accurate** | Decimal degrees, e.g. `-69.9633227139`. Western longitudes are negative. |
| `height` | number | **Required, must be accurate** | Antenna height in meters, **ellipsoidal** (WGS84), not orthometric/MSL height. If you only have an orthometric height, you need to apply your local geoid model's separation value to convert it, or use an ellipsoidal height directly from your GNSS survey. |

## Marker / antenna

These describe the physical monument and antenna, used for RINEX header
metadata (important for anyone else who later uses your RINEX files) and
have no effect on the GNSS-IR analysis itself.

| Field | Type | Required? | Description |
|---|---|---|---|
| `marker_name` | string | Recommended | Usually the same as `station_id`. |
| `marker_number` | string | Recommended | Usually the same as `station_id`. |
| `antenna.model` | string | Recommended | Antenna model, e.g. `"AS-ANT3B-BUDSUR-L1L2L5-25SMA"`. |
| `antenna.serial` | string | Optional | Antenna serial number. |
| `antenna.height` | number | Optional | Antenna offset height above the marker, meters. Default `0.0`. |
| `antenna.east_offset` | number | Optional | East offset from the marker, meters. Default `0.0`. |
| `antenna.north_offset` | number | Optional | North offset from the marker, meters. Default `0.0`. |

## RINEX

| Field | Type | Required? | Description |
|---|---|---|---|
| `rinex_version` | string | Recommended | RINEX version to produce, e.g. `"3.05"`. RINEX 3 is required for this project's RINEX-3-specific station code handling to work correctly (see `gnssrefl_monument_number`/`gnssrefl_country_code` below). |

## Recording

| Field | Type | Required? | Description |
|---|---|---|---|
| `record_raw_chunk_seconds` | integer | Recommended | How long each recording "chunk" is, in seconds, during continuous unattended operation (`station_manager.py`). Recording happens in chunks rather than one call per day so a shutdown request only has to wait for the current chunk to finish, not the whole day. `600` (10 minutes) is a reasonable default; `3600` (1 hour) trades slightly slower shutdown response for slightly less overhead. |

## gnssrefl station code

gnssrefl's own RINEX-processing tools require a station identifier of an
*exact* length depending on RINEX version — 4 characters for RINEX 2.11,
9 characters for RINEX 3. This project handles that automatically, but
these settings let you override the automatic derivation if needed.

| Field | Type | Required? | Description |
|---|---|---|---|
| `gnssrefl_station_code` | string, exactly 4 chars | Optional | The 4-character code gnssrefl uses internally. If not set, it's derived automatically from the first 4 characters of `station_id`, lowercased. Only set this by hand if that automatic derivation isn't right for you. |
| `gnssrefl_monument_number` | string, 2 chars | Optional | Used to build the 9-character RINEX 3 station code (4-char code + monument number + country code). Default `"00"`. |
| `gnssrefl_country_code` | string, 3 chars | Optional | Same purpose as above. Default `"usa"`. |

## Orbit source

| Field | Type | Required? | Description |
|---|---|---|---|
| `gnssrefl_orbit_source` | string | Optional | Leave unset for gnssrefl's own default: automatic multi-GNSS SP3 orbit downloads from CDDIS, covering GPS, GLONASS, Galileo, and BeiDou. Set to `"nav"` only if you need offline-friendlier GPS-only broadcast ephemeris instead (confirmed to roughly **halve** the number of usable satellite tracks compared to the multi-GNSS default — only use this if you have a specific reason to, such as no reliable internet access, or needing same-day results before that day's multi-GNSS orbit product has been published, which routinely takes 1-2 days). |

## Sample rate and constellations

| Field | Type | Required? | Description |
|---|---|---|---|
| `gnssrefl_sample_rate` | integer | Recommended | Must match your receiver's actual logging rate, in seconds. `1` (1 Hz) is standard. |
| `gnssrefl_all_frequencies` | boolean | Strongly recommended: `true` | Whether to analyze all constellations and frequencies (GPS + GLONASS + Galileo + BeiDou) rather than GPS-only. Confirmed to make a large, real difference in data density — leaving this `false` (gnssrefl's own internal default) silently discards most of what your receiver actually captured. |

---

## Advanced gnssrefl tuning (all optional)

Everything below has a sensible gnssrefl-internal default. Only change
these if you have a specific, understood reason to — an obstructed view,
an unusually tall or short site, a noisy environment, or a site with very
fast water-level changes. Leaving a field out of `station.json` entirely
means gnssrefl's own default applies, unchanged.

### Elevation angle mask

| Field | Type | Description |
|---|---|---|
| `gnssrefl_elevation_min` | number (degrees) | Minimum satellite elevation angle to analyze. gnssrefl's own default is roughly 5°. |
| `gnssrefl_elevation_max` | number (degrees) | Maximum satellite elevation angle to analyze. gnssrefl's own default is roughly 25°. |

A narrower window (e.g. 5–15°) generally means a *closer*, lower reflection
footprint — useful for a site with a limited clear view, but also means
fewer minutes of data per satellite pass and a smaller pool of usable
tracks (see `gnssrefl_direct_signal_poly_order` and
`gnssrefl_elevation_span_tolerance` below, which usually need adjusting
together with a narrow window like this).

### Reflector height search range

| Field | Type | Description |
|---|---|---|
| `gnssrefl_reflector_height_min` | number (meters) | Minimum reflector height to search for. gnssrefl's own default is roughly 0.5m. |
| `gnssrefl_reflector_height_max` | number (meters) | Maximum reflector height to search for. gnssrefl's own default is roughly 8m. |

This is the vertical distance gnssrefl searches for a reflecting surface
below the antenna — set this to comfortably bracket your antenna's real
height above whatever you're trying to sense (water, soil, snow),
including its full range of expected motion (e.g. full tidal range for a
coastal site).

**Important, confirmed technical detail:** if you set both of these,
this project automatically keeps gnssrefl's internal noise-floor
estimation region (`nr1`/`nr2`) in sync with them. Without this, widening
this range without knowing to *also* widen the noise region separately
causes every single retrieval to silently fail with no clear error — this
project handles that automatically as long as both `_min` and `_max` are
set together.

### Azimuth mask

| Field | Type | Description |
|---|---|---|
| `gnssrefl_azimuth_regions` | list of numbers (degrees) | Which compass directions have a genuinely clear view, as a flat list of region boundaries. Default (unset) is the full circle, `[0, 360]`. |

If part of your view is blocked (a building, trees, rising terrain), list
only the clear region(s). For example, `[0, 150, 180, 360]` analyzes
0°–150° and 180°–360°, excluding the 150°–180° range. This can wrap
through north: `[353, 360, 0, 173]` analyzes 353°–360° and 0°–173°
(i.e., roughly northwest through south, wrapping across due north).

### Quality control thresholds

| Field | Type | Description |
|---|---|---|
| `gnssrefl_peak2noise` | number | Minimum peak-to-noise ratio for a retrieval to be accepted. gnssrefl's own default is roughly 2.8. Raising this is stricter (fewer, higher-confidence retrievals); lowering it is more permissive. |
| `gnssrefl_amplitude_min` | number | Minimum signal amplitude for a retrieval to be accepted. gnssrefl's own default is roughly 5.0. |

### Orthometric height reference

| Field | Type | Description |
|---|---|---|
| `gnssrefl_orthometric_height` | number (meters) | Your antenna's height above a specific vertical datum (e.g. NAVD88, a local tide gauge datum). If set, gnssrefl reports real, absolute water level relative to this datum instead of just a relative reflector height. Meaningful for coastal sites; not typically applicable to interior lakes/rivers with no established local datum. **Check which height system the number is in.** A CSRS-PPP report gives CGVD2013 (Canadian), not NAVD88: for this station PPP said 18.665 m, NGS OPUS said 19.014 m NAVD88 (GEOID18), so every water level was 0.349 m low. Use an OPUS (or other NAVD88/GEOID18) height for US sites. See `station_datum.py`. |

### Refraction model

| Field | Type | Description |
|---|---|---|
| `gnssrefl_refraction_model` | integer | Which tropospheric refraction correction to apply (passed to gnssrefl as `refr_model`). `1` (gnssrefl's own default) is the standard Bennett correction; `0` turns refraction off. Leave unset unless you have a specific, understood reason to change it. |

### Maximum arc length

| Field | Type | Description |
|---|---|---|
| `gnssrefl_max_arc_minutes` | number (minutes) | Maximum duration of a single satellite pass to include in one retrieval. gnssrefl's own default is 75 minutes, which is documented as too long for a site with a fast tidal (or other water-level) rate of change — a single retrieval's reflector-height estimate gets blurred across however much real change happens during that whole window. Consider a much shorter value (e.g. 20–40) for a site with strong or fast tides. |

### Arc elevation-span tolerance

| Field | Type | Description |
|---|---|---|
| `gnssrefl_elevation_span_tolerance` | number (degrees) | How close to your full elevation range (above) a satellite pass must actually reach to be accepted. **Smaller is stricter.** gnssrefl's own default is 2 — with an elevation mask of 5–15°, a pass must span at least 7–13°. At `1` it must span 6–14°, which rejects more passes. gnssrefl's docs suggest `1` for a narrow 5–15° mask to keep only arcs that cover the window; raise it (e.g. back to 2) if you see too few retrievals. |

### Direct-signal removal polynomial order

| Field | Type | Description |
|---|---|---|
| `gnssrefl_direct_signal_poly_order` | integer | Order of the polynomial fit used to remove the antenna's own direct-signal gain trend from the raw data before the real reflection analysis begins. gnssrefl's own default is 4. A narrow elevation mask gives each pass less raw data to fit against, which can make this default numerically unstable — if you see a `RankWarning: The fit may be poorly conditioned` message in your processing output, lowering this (e.g. to `2`) is the standard, documented fix. |

---

## External storage (optional)

| Field | Type | Description |
|---|---|---|
| `external_storage_path` | string (path) | If set, each day's raw data and processed results are automatically moved here after processing, during continuous unattended operation. Leave unset to disable this entirely — everything stays local. |
| `manager_retry_delay_seconds` | number | How long to wait before retrying after a failed recording chunk, during continuous operation. Default `60.0`. |
| `health_check_interval_seconds` | number | How often to record a system health snapshot (disk space, CPU, memory) during continuous operation. Default `3600.0` (1 hour). |
| `export_retry_window_days` | integer | How many days to keep retrying a day's export to external storage before giving up (this exists because a day's orbit product routinely isn't published for 1-2 days after the fact, so an immediate export would predictably fail). Default `3`. |

---

## A complete, real example

This is a genuine, working configuration (with the identifying details
changed), showing which fields a real deployment actually used:

```json
{
    "station_id": "USGS001",
    "station_name": "Example Station",
    "agency": "USGS",
    "observer": "J. Researcher",
    "receiver_model": "Unicore UM980",
    "receiver_firmware": "",
    "receiver_port": "/dev/USB_GPS",
    "receiver_baud": 115200,
    "receiver_timeout": 2.0,
    "latitude": 41.8928243333,
    "longitude": -69.9633227139,
    "height": -10.025,
    "marker_name": "USGS001",
    "marker_number": "USGS001",
    "rinex_version": "3.05",
    "antenna": {
        "model": "AS-ANT3B-BUDSUR-L1L2L5-25SMA",
        "serial": "",
        "height": 0.0,
        "east_offset": 0.0,
        "north_offset": 0.0
    },
    "record_raw_chunk_seconds": 600,
    "gnssrefl_sample_rate": 1,
    "gnssrefl_all_frequencies": true,
    "gnssrefl_monument_number": "00",
    "gnssrefl_country_code": "usa",
    "gnssrefl_elevation_min": 5.0,
    "gnssrefl_elevation_max": 15.0,
    "gnssrefl_reflector_height_min": 17.0,
    "gnssrefl_reflector_height_max": 23.0,
    "gnssrefl_orthometric_height": 19.014,
    "gnssrefl_max_arc_minutes": 40.0,
    "gnssrefl_elevation_span_tolerance": 1.0,
    "gnssrefl_direct_signal_poly_order": 2,
    "gnssrefl_azimuth_regions": [353, 360, 0, 173],
    "external_storage_path": "/mnt/external_storage/GPS_Data"
}
```

Notice this real example uses a narrow, non-default elevation mask
(5–15°) and correspondingly tightens `gnssrefl_elevation_span_tolerance`
(to `1.0`, stricter than the default 2) and lowers `gnssrefl_direct_signal_poly_order` (to `2`) —
exactly the paired adjustment described above for a narrow window. If you
copy this file as a starting point for your own station, **change the
location fields first** — everything else can reasonably stay at these
values until you have a specific reason to change them.

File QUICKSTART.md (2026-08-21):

# Quickstart: GNSS-IR Reference Station

This guide walks you through setting up a working GNSS-IR (GNSS
Interferometric Reflectometry) reference station from a completely bare
machine to your first real plot, with no prior experience assumed.

GNSS-IR uses the same signals a regular GPS receiver already gets from
satellites, but analyzes how they *reflect* off a nearby surface (water,
soil, snow) before reaching the antenna. That reflection shows up as a
subtle interference pattern in the raw signal strength data, and from that
pattern, this software can work out how far below the antenna the
reflecting surface is — and therefore, over time, how that distance
(water level, soil moisture, snow depth) is changing.

---

## What you'll need

- A Linux machine (this guide assumes Ubuntu or a close relative — see
  the note in `install.sh` if you're on something else)
- A supported GNSS receiver (this project was built and tested against a
  Unicore UM980; other receivers may need changes to `station/receiver.py`)
- A GNSS antenna, mounted somewhere with a reasonably clear view of the
  sky and, ideally, of whatever you're trying to sense (open water,
  bare soil, snow-covered ground)
- Your antenna's precise location: latitude, longitude, and height. If
  you don't have a survey-grade position yet, even a consumer GPS
  reading is enough to get started and see real results — you can
  refine the location later without losing any collected data, since
  GNSS-IR reprocesses from the same raw recordings
- Internet access on the machine (used to download orbit data and
  install software; a single well-configured continuous connection is
  ideal, but the software tolerates intermittent connectivity)

---

## Step 1: Install everything

From the project directory:

```bash
./install.sh
```

This checks for, and installs if missing:
- Python and a private virtual environment for this project (so it
  can't conflict with anything else on your system)
- `git` and build tools
- RTKLIB's `convbin` (built from source — this project needs a specific
  version, not the one available via your system's package manager;
  `install.sh` explains why and handles this automatically)
- `gnssrefl`, the GNSS-IR analysis engine this project is built on
- This project's own directory structure (`raw/`, `rinex/`, `products/`,
  etc.)

It will ask before making any change that needs administrator (`sudo`)
access, and is safe to re-run if it's interrupted partway through —
every step checks whether it's already done before doing it again.

At the end, it will automatically start the **station configuration
wizard** (`setup_station.sh`) if you don't already have a
`station.json` file. Answer its questions about your station's
identity, receiver, and — most importantly — its exact location. See
**`STATION_JSON_REFERENCE.md`** for a complete explanation of every
setting if you want more detail than the wizard gives inline, or if you
need to change something later by hand.

---

## Step 2: Verify everything is working

```bash
./test_installation.sh
```

This checks the Python environment, every required tool, your
configuration file, the project's internal file layout, and (if a
receiver happens to be connected already) basic communication with it.
It gives a clear pass/fail for each check with a plain-language
explanation of what to do about anything that failed — fix those before
moving on.

It's normal, and not a failure, to see a warning here if your receiver
isn't connected yet. This step is meant to be useful even before you
have hardware set up.

---

## Step 3: Connect your receiver

Plug in your receiver via USB (or however your specific model connects).
Confirm your operating system sees it:

```bash
dmesg | tail -20
```

You should see a new serial device appear, e.g. `/dev/ttyUSB0` or
`/dev/ttyACM0`.

**Strongly recommended:** set up a stable, named symlink (like
`/dev/USB_GPS`, the default this project expects) rather than using the
raw device name directly, since that name can change across reboots or
if other USB devices are plugged in. This is normally done with a
`udev` rule based on your receiver's specific USB vendor/product ID —
consult your receiver's documentation, or your Linux distribution's
udev documentation, for the exact steps, since these details vary by
hardware. Once set up, update `receiver_port` in `station.json` (or
re-run `./setup_station.sh`) to match.

---

## Step 4: A quick connectivity check (optional but recommended)

Before committing to a long recording, confirm the receiver responds:

```bash
source gnssrefl_venv/bin/activate
python3 station/tools/um980_cmd.py VERSIONA
```

You should see the receiver's model and firmware printed back. If this
times out or errors, double check `receiver_port` and
`receiver_baud` in `station.json`, and that nothing else (another
program, a stale terminal session) already has the port open.

You can also check basic antenna position stability before a long
unattended run:

```bash
python3 station/position_stability_check.py --duration 300
```

---

## Step 5: Record some data

**For a first test**, a recording of an hour or more is enough to see
whether the whole pipeline works end-to-end (though a real, useful
result — especially for something slowly changing like soil moisture —
usually needs many hours to days of data). To record for a specific,
fixed duration:

```bash
cd station
python3 overnight_recording.py --hours 4
```

This can run for as long as you like; run it inside `screen` or `tmux`
if you're connecting over SSH, since it needs to keep running even if
your connection drops:

```bash
screen -S gnss_recording
source ../gnssrefl_venv/bin/activate
python3 overnight_recording.py --hours 4
# Ctrl+A, D to detach; "screen -r gnss_recording" to reattach later
```

**For continuous, unattended, indefinite operation** (the normal way to
actually run a reference station long-term), see **Step 8** below
instead of this manual recording step.

---

## Step 6: Process your data and see a plot

Once you have at least a little recorded data:

```bash
./process_and_plot.sh
```

This one command:
1. Recovers any previously-missed days, if you've configured external
   storage
2. Converts new raw recordings to RINEX and runs the GNSS-IR analysis
3. Finds the most recent stretch of results and generates a plot

You'll see live progress throughout — a count of how many files have
been processed so far, and gnssrefl's own detailed per-day output as it
runs. Processing genuinely takes real time (RINEX conversion plus
orbit-data-dependent analysis, per file) — this is expected, not a
sign that anything has stalled.

When it finishes, it tells you exactly where the plots were saved. The
main result is usually the file ending in `_last.png`.

---

## Step 7: Understand what you're looking at

The main plot shows your computed reflector height (or, if you set
`gnssrefl_orthometric_height` in `station.json`, absolute water level)
over time. A few things worth knowing before you trust what you see:

- **A handful of data points from one day is not a signal.** Real,
  useful GNSS-IR results generally need many satellite passes across
  many hours to start showing a clear, physically consistent pattern.
- **Not every day will produce results, and that's normal.** Depending
  on your elevation mask, azimuth mask, and site geometry, some days
  simply won't have enough usable satellite passes. This project's
  tooling (`recover_missing_days.sh`) distinguishes this genuine
  "no data" outcome from a transient failure (like a not-yet-published
  orbit product) automatically.
- **A pattern that correlates with something external does not by
  itself prove the antenna is sensing that thing.** Before trusting a
  result, especially one you plan to publish or rely on, use
  `validate_station.py` (next step) to check whether the pattern you're
  seeing is actually geometry-specific (as real reflection sensing
  should be), or a shared artifact that shows up regardless of
  direction (which would suggest something else — an atmospheric
  effect, an instrumental artifact, a processing issue — not genuine
  sensing).

---

## Step 8: Check whether your results are real

```bash
python3 validate_station.py --checks reflection-zone \
    --center-azimuth <bearing toward your target, in degrees>
```

This generates a KML file you can open in Google Earth, showing exactly
where your antenna's reflection footprint actually falls at different
water levels (or ground conditions) — useful for confirming your
azimuth mask and reflector-height range are physically sensible before
you trust anything downstream.

If you have an independent reference signal to compare against (a
nearby tide gauge, a soil moisture sensor, a weather station), you can
run the tool's other checks (`azimuth`, `elevation`, `refraction`) to
test whether an apparent signal is genuinely geometry-specific — see
the comments at the top of `validate_station.py` for the full
methodology and how to run each check.

---

## Step 9: Go continuous (optional, for long-term deployment)

Once you're confident the whole pipeline works, `station_manager.py`
runs the station continuously and unattended — recording in
configurable chunks, processing automatically, and (if configured)
exporting to external storage:

```bash
cd station
python3 station_manager.py
```

For a truly hands-off deployment, `start_station.sh` and
`stop_station.sh` provide an idempotent wrapper suitable for running
from `cron` as a watchdog (so an unexpected crash gets automatically
restarted, without ever risking two copies fighting over the same
serial port):

```bash
crontab -e
# Add a line like:
# @reboot /path/to/station/start_station.sh
# */5 * * * * /path/to/station/start_station.sh
```

To stop gracefully (waiting for the current recording chunk to finish,
rather than an abrupt kill):

```bash
station/stop_station.sh
```

---

## Troubleshooting

**"No results found" after processing, but no errors either.**
Most likely, none of your recorded days had enough usable satellite
passes to produce a retrieval — a genuine, normal outcome for some
site/configuration combinations, not necessarily a bug. Check your
elevation and azimuth mask in `station.json` against your site's real,
physical sky view.

**Very few retrievals per day, or a `RankWarning` in the processing
output.**
If you're using a narrow elevation mask (a small range between
`gnssrefl_elevation_min` and `gnssrefl_elevation_max`), see the
"Elevation angle mask" section of `STATION_JSON_REFERENCE.md` — this is
a documented, expected tradeoff with a known fix
(`gnssrefl_elevation_span_tolerance`, `gnssrefl_direct_signal_poly_order`).

**Results look confident but implausible (wrong magnitude, wrong
timing).**
Double-check `latitude`/`longitude`/`height` in `station.json` first —
these are the single most common source of confusing results, since an
error here doesn't cause a processing failure, just a wrong answer.

**"convbin not found" or receiver connection errors.**
Re-run `./test_installation.sh` for a clear diagnosis, then
`./install.sh` again if needed — both are safe to re-run at any time.

**Something else.**
Every script's own header comment explains what it does and why, in
detail — `station/gnssrefl_processor.py` and `station/receiver.py` in
particular document several confirmed, real quirks of both gnssrefl and
the receiver hardware that are worth reading if you're debugging
something unusual.

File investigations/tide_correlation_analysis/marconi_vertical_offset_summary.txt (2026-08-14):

MARCONI GNSS-R vs EOT20 VERTICAL OFFSET ANALYSIS
============================================================================================
Primary tide model: EOT20_heightm
H_ortho: 18.665 m

POPULATION RESULT
--------------------------------------------------------------------------------------------
n               : 465
mean_m          : -0.2045 m (-20.45 cm)
median_m        : -0.2224 m (-22.24 cm)
std_m           : +0.3494 m (+34.94 cm)
rms_m           : +0.4048 m (+40.48 cm)
mae_m           : +0.3018 m (+30.18 cm)
MAD_m           : +0.2908 m (+29.08 cm)
r               : 0.8686346114262107
slope           : 0.8864951096666772

PERSISTENT TRACK OFFSETS
--------------------------------------------------------------------------------------------
PRN  2 SETTING Az=  52.89±0.05° N=17 days=17 median=-0.3942 m mean=-0.2518 m SD=0.2786 m RMS=0.3756 m r=+0.9070 slope=+0.9279
PRN 20 SETTING Az=  69.88±0.10° N=20 days=20 median=-0.3618 m mean=-0.3201 m SD=0.2482 m RMS=0.4051 m r=+0.9267 slope=+0.9417
PRN  8 SETTING Az=  83.44±0.12° N=17 days=17 median=-0.3431 m mean=-0.3082 m SD=0.2533 m RMS=0.3989 m r=+0.9438 slope=+1.0099
PRN 30 RISING  Az= 102.97±0.02° N=18 days=18 median=-0.3247 m mean=-0.2758 m SD=0.2103 m RMS=0.3468 m r=+0.9354 slope=+0.9495
PRN 15 SETTING Az=  93.26±0.19° N=22 days=22 median=-0.3173 m mean=-0.2741 m SD=0.3186 m RMS=0.4203 m r=+0.8681 slope=+0.8518
PRN  5 SETTING Az= 117.33±0.20° N=17 days=17 median=-0.3170 m mean=-0.2832 m SD=0.2386 m RMS=0.3703 m r=+0.9339 slope=+0.8960
PRN 27 SETTING Az=  63.43±0.01° N=15 days=15 median=-0.3095 m mean=-0.2882 m SD=0.2217 m RMS=0.3636 m r=+0.9560 slope=+0.9426
PRN 24 SETTING Az=  57.25±0.06° N=23 days=23 median=-0.2957 m mean=-0.2340 m SD=0.2569 m RMS=0.3475 m r=+0.9233 slope=+0.8009
PRN  6 SETTING Az= 114.73±0.13° N=18 days=18 median=-0.2855 m mean=-0.3107 m SD=0.2515 m RMS=0.3997 m r=+0.9088 slope=+0.9347
PRN 12 RISING  Az= 133.25±0.06° N= 4 days= 4 median=-0.2743 m mean=-0.2719 m SD=0.0569 m RMS=0.2777 m r=+0.9098 slope=+0.6111
PRN 29 RISING  Az= 113.01±0.04° N=23 days=23 median=-0.2738 m mean=-0.2627 m SD=0.1637 m RMS=0.3095 m r=+0.9765 slope=+0.9455
PRN  1 SETTING Az=  56.24±0.06° N=17 days=17 median=-0.2689 m mean=-0.2343 m SD=0.2896 m RMS=0.3725 m r=+0.8813 slope=+0.8612
PRN 16 SETTING Az=  96.48±0.06° N=15 days=15 median=-0.2555 m mean=-0.2883 m SD=0.2682 m RMS=0.3938 m r=+0.9241 slope=+0.8777
PRN 21 SETTING Az=  92.84±0.17° N=19 days=19 median=-0.2436 m mean=-0.3260 m SD=0.2555 m RMS=0.4142 m r=+0.9219 slope=+0.9499
PRN  4 RISING  Az=  96.33±0.02° N=17 days=17 median=-0.2404 m mean=-0.2463 m SD=0.1966 m RMS=0.3151 m r=+0.9459 slope=+0.8927
PRN  9 RISING  Az= 124.46±0.04° N=17 days=17 median=-0.2215 m mean=-0.2244 m SD=0.1357 m RMS=0.2622 m r=+0.9759 slope=+0.9973
PRN 31 SETTING Az= 127.05±0.06° N= 8 days= 8 median=-0.2165 m mean=-0.2879 m SD=0.2079 m RMS=0.3551 m r=+0.9078 slope=+0.9667
PRN 13 SETTING Az=  38.84±0.07° N=12 days=12 median=-0.2023 m mean=-0.1759 m SD=0.1831 m RMS=0.2539 m r=+0.9719 slope=+0.8876
PRN 30 SETTING Az=  33.75±0.01° N=17 days=17 median=-0.1947 m mean=-0.2878 m SD=0.2504 m RMS=0.3815 m r=+0.9335 slope=+0.9440
PRN  9 SETTING Az=  35.02±0.01° N=17 days=17 median=-0.1798 m mean=-0.2133 m SD=0.1560 m RMS=0.2642 m r=+0.9699 slope=+1.0317
PRN  3 SETTING Az=  37.18±0.04° N=16 days=16 median=-0.1725 m mean=-0.1616 m SD=0.2116 m RMS=0.2663 m r=+0.9439 slope=+0.8079
PRN  4 SETTING Az=  30.52±0.01° N=15 days=15 median=-0.1610 m mean=-0.2133 m SD=0.1843 m RMS=0.2818 m r=+0.9596 slope=+0.9360
PRN 26 SETTING Az=  90.71±0.16° N=14 days=14 median=-0.1517 m mean=-0.2509 m SD=0.2623 m RMS=0.3629 m r=+0.9113 slope=+0.9112
PRN 29 SETTING Az=  33.33±0.01° N=13 days=13 median=-0.1405 m mean=-0.1801 m SD=0.1961 m RMS=0.2662 m r=+0.9591 slope=+0.9637
PRN 25 SETTING Az=  47.61±0.02° N=16 days=16 median=-0.1268 m mean=-0.2104 m SD=0.1849 m RMS=0.2801 m r=+0.9706 slope=+0.9082
PRN 12 SETTING Az=  37.54±0.01° N=21 days=21 median=-0.1212 m mean=-0.1657 m SD=0.2036 m RMS=0.2626 m r=+0.9657 slope=+0.8824
PRN 28 SETTING Az= 114.24±0.07° N=15 days=15 median=-0.1144 m mean=-0.2158 m SD=0.2243 m RMS=0.3113 m r=+0.9414 slope=+0.9322
PRN 19 SETTING Az= 148.97±0.11° N=12 days=12 median=+1.3494 m mean=+1.2211 m SD=0.6127 m RMS=1.3662 m r=+0.0016 slope=+0.0001

DATUM INTERPRETATION
--------------------------------------------------------------------------------------------
This analysis quantifies the observed vertical separation.
It does NOT label that separation as a NAVD88-to-MSL datum shift.
A constant offset is consistent with a reference-level difference,
but reflector-height bias, model reference conventions, local
mean-water level, and other systematic effects can also contribute.

A useful next comparison is the observed population/track offset
against an independently established Marconi local MSL/MLLW/
NAVD88 relationship.

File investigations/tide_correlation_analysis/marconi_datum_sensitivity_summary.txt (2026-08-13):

MARCONI TIDE DATUM INVESTIGATION / ±0.50 m SENSITIVITY
============================================================================================
Topobathy: 2021022FA_Marconi_topobathy_1m.tif
Tide workbook: marconi_tides_sherwood.xlsx
Footprint elevation: 13.0 deg
Shift range: -0.50 to +0.50 m

IMPORTANT DATUM FINDING
The tide-model columns in the workbook are tidal signals
centered near zero. They must not be interpreted as NAVD88
absolute water elevations without an independently established
local vertical datum offset.

TRACK / MODEL SHIFT SENSITIVITY
--------------------------------------------------------------------------------------------
PRN26_AZ91       EOT20_heightm      best80_shift=+0.15 m mean_wet=0.803 >=80% band=+0.15 to +0.50 m
PRN26_AZ91       GOT5.5_heightm     best80_shift=+0.10 m mean_wet=0.796 >=80% band=+0.15 to +0.50 m
PRN26_AZ91       GOT5.6_heightm     best80_shift=+0.15 m mean_wet=0.799 >=80% band=+0.20 to +0.50 m
PRN26_AZ91       FES2022_heightm    best80_shift=+0.15 m mean_wet=0.799 >=80% band=+0.20 to +0.50 m
PRN21_AZ93       EOT20_heightm      best80_shift=+0.20 m mean_wet=0.792 >=80% band=+0.25 to +0.50 m
PRN21_AZ93       GOT5.5_heightm     best80_shift=+0.20 m mean_wet=0.810 >=80% band=+0.20 to +0.50 m
PRN21_AZ93       GOT5.6_heightm     best80_shift=+0.20 m mean_wet=0.796 >=80% band=+0.25 to +0.50 m
PRN21_AZ93       FES2022_heightm    best80_shift=+0.20 m mean_wet=0.795 >=80% band=+0.25 to +0.50 m
PRN16_AZ96       EOT20_heightm      best80_shift=+0.50 m mean_wet=0.808 >=80% band=+0.50 to +0.50 m
PRN16_AZ96       GOT5.5_heightm     best80_shift=+0.50 m mean_wet=0.791 >=80% band=none in ±0.50 m
PRN16_AZ96       GOT5.6_heightm     best80_shift=+0.50 m mean_wet=0.803 >=80% band=+0.50 to +0.50 m
PRN16_AZ96       FES2022_heightm    best80_shift=+0.50 m mean_wet=0.796 >=80% band=none in ±0.50 m

INTERPRETATION
The shift sweep is a sensitivity analysis, not a calibration.
Do not choose a datum shift solely because it maximizes water
fraction. The final offset must come from the independently
established relationship between the tide-model datum and the
USGS NAVD88 topobathy datum / local water-level reference.

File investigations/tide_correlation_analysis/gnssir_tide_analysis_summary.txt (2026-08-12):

USGS GNSS-IR / TIDE MODEL ANALYSIS
======================================================================
Station: usgs
Year: 2026
DOY: 204-207
Reference height: 18.625000 m
Total extracted: 1356
QC passing: 1352
Final paired arcs: 82

ARC SETTINGS
e1=5.0
e2=15.0
azlist=[353,360,0,173]
polyV=2
pele=[5,30]
attach_results=True
buffer_hours=2

QC DEFINITION
meta['gnssir_processing_results'] is not None

ZERO-LAG PHYSICAL COMPARISON
GNSS water level = H_reference - RH
Comparison = tide + constant offset
offset_m=17.172871067
RMS_cm=72.382598
MAE_cm=57.026485
mean_bias_cm=-0.000000
correlation=-0.163056855

SOLUTION EPOCH RELATIVE TO ARC MIDPOINT
min_sec=-20.004800
median_sec=4.258000
mean_sec=2.000702
max_sec=23.463200

TIMING LAG SEARCH
search_range_minutes=[-300, 300]
best_lag_minutes=-300.000000
best_rms_cm=71.301819
zero_lag_rms_cm=72.382598
rms_improvement_cm=1.080779

WITHIN-ARC TIDAL CHANGE
minimum_cm=0.600778
mean_cm=13.640021
median_cm=13.078234
maximum_cm=25.511918
percent_over_2cm=95.121951
percent_over_5cm=87.804878
percent_over_10cm=73.170732

WITHIN-ARC TIDAL-SMEARING TEST
pearson_error_vs_abs_tide_change=-0.281546448
spearman_error_vs_abs_tide_change=-0.317990858
pearson_error_vs_duration=0.153034789
spearman_error_vs_duration=0.093750000
pearson_error_vs_abs_tide_rate=-0.376495103

TIDAL MOVEMENT BINS
0-2 cm: n=4, mean_abs_error_cm=88.028309, median_abs_error_cm=83.311593, rms_cm=104.689539
2-5 cm: n=6, mean_abs_error_cm=67.763051, median_abs_error_cm=65.902689, rms_cm=71.513700
5-10 cm: n=12, mean_abs_error_cm=73.475755, median_abs_error_cm=56.849289, rms_cm=84.826242
10-20 cm: n=42, mean_abs_error_cm=57.299780, median_abs_error_cm=50.830840, rms_cm=73.457136
>20 cm: n=18, mean_abs_error_cm=34.954465, median_abs_error_cm=30.398754, rms_cm=48.371846

RISING/FALLING
RISING: n=45, signed_mean_cm=-7.334790, mean_abs_error_cm=58.347419
FALLING: n=37, signed_mean_cm=8.920691, mean_abs_error_cm=55.419943

FREQUENCY SUMMARY
freq=1: n=17, mean_abs_error_cm=64.968910, rms_cm=77.444936, error_tide_change_r=-0.497907
freq=5: n=4, mean_abs_error_cm=79.356818, rms_cm=116.845317, error_tide_change_r=-0.184476
freq=20: n=3, mean_abs_error_cm=23.559129, rms_cm=27.950564, error_tide_change_r=0.099369
freq=101: n=23, mean_abs_error_cm=50.973443, rms_cm=65.056849, error_tide_change_r=-0.369431
freq=102: n=2, mean_abs_error_cm=124.170670, rms_cm=132.824077, error_tide_change_r=nan
freq=201: n=12, mean_abs_error_cm=58.750663, rms_cm=73.823639, error_tide_change_r=-0.538943
freq=205: n=6, mean_abs_error_cm=54.927880, rms_cm=65.172162, error_tide_change_r=-0.352104
freq=207: n=5, mean_abs_error_cm=52.425709, rms_cm=58.948742, error_tide_change_r=-0.885718
freq=302: n=10, mean_abs_error_cm=46.616130, rms_cm=54.601821, error_tide_change_r=-0.199798

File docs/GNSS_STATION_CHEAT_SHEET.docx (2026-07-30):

GNSS-R Water Level Station — Master Cheat Sheet

This document is meant to let anyone — with zero prior experience on this project — operate the station, process data, generate plots, and compare against real tide references. Every command below has actually been run and verified on the real system.

Station: USGS001 / "Marconi", gnssrefl station code usgs

Machine location (on the NUC): everything lives under /home/argus_user/, shown below as ~ throughout (so ~ = /home/argus_user).

# 1. Quick Start — the one command you'll use most

source ~/run_and_view.sh

Processes any new data, overlays it against the real tide models, and lands you directly in the folder with every plot -- see 3.1 below for full detail (including why source specifically matters here).

To just check the station is alive without processing anything:

ps aux | grep station_manager.py | grep -v grep

tail -10 ~/GNSS/v4.1/logs/station_manager.out

# 2. File Structure — where everything lives

## 2.1 Project root: ~/GNSS/v4.1/

Full path | What it is | Written by | Read by
~/GNSS/v4.1/raw/ | Raw receiver data, one file per day: station_YYYYMMDD.um980. Written continuously in 600-second chunks while recording. | station_manager.py (live recording) | pipeline.py (RINEX conversion)
~/GNSS/v4.1/rinex/ | Converted RINEX observation/navigation files (.obs, .nav, .sbs) — intermediate, working files | rinex_processor.py during processing | gnssrefl_processor.py
~/GNSS/v4.1/archive/ | Raw .um980 files get moved here after being successfully processed | pipeline.py's archive step | Nothing normally — historical record only
~/GNSS/v4.1/database/station.db | SQLite database tracking every raw file, every RINEX conversion attempt, and the processing queue | database.py | pipeline.py, diagnostic queries
~/GNSS/v4.1/logs/station_manager.out | Our own system's live log — receiver connection, recording status, errors | station_manager.py | You, when checking health
~/GNSS/v4.1/logs/database.log | Database-specific log | database.py | Rarely needed directly
~/GNSS/v4.1/station/ | All Python source code + shell scripts (see 2.3) | — | —
~/GNSS/v4.1/station/resources/station.json | The master configuration file — coordinates, receiver settings, every gnssrefl tuning parameter | You (via setup_station.sh or direct edit) | Everything
~/GNSS/v4.1/tests/ | Automated test suite | — | process_gps_data.sh Step 1
~/GNSS/v4.1/docs/USER_MANUAL.docx | Full narrative setup/user manual | — | New users
~/GNSS/v4.1/gnssrefl_venv/ | The Python virtual environment — has matplotlib, gnssrefl, etc. installed | — | Every Python command needs this activated
~/GNSS/v4.1/setup_station.sh | Interactive configuration wizard | — | You, when reconfiguring
~/GNSS/v4.1/compare_to_noaa.py | Overlays GNSS-IR water level against a calendar-style tide chart (CSV) | — | You
~/GNSS/v4.1/compare_to_tide_models.py | Overlays GNSS-IR water level against real scientific tide models (Excel). Automatically finds and uses the most recently modified spline output, whether local or already exported. | — | You
~/GNSS/v4.1/tides_1_2026-07.csv | Real NOAA-style monthly tide chart, in feet — read by compare_to_noaa.py by default | Uploaded by you | compare_to_noaa.py
~/GNSS/v4.1/marconi_tides_sherwood.xlsx | Real site-specific tide model predictions (EOT20, GOT5.5, GOT5.6, FES2022), in meters | Uploaded by you | compare_to_tide_models.py
~/GNSS/v4.1/recover_missing_days.sh | Recovers day-of-year data the automatic pipeline missed because its orbit product wasn't published yet before export | — | You, occasionally

## 2.2 gnssrefl's own working directory: ~/GNSS/v4.1/products/refl_code/

This entire tree is what gnssrefl calls $REFL_CODE. It gets regenerated from scratch after each export (see 2.4), so don't rely on anything here being permanent.

Full path | What it is
~/GNSS/v4.1/products/refl_code/2026/results/usgs/<doy>.txt | Daily reflector-height results — one file per day-of-year (e.g. 199.txt = July 18). The core scientific output before plotting.
~/GNSS/v4.1/products/refl_code/2026/results/usgs/failQC/ | Arcs that failed quality control, kept for diagnostic purposes
~/GNSS/v4.1/products/refl_code/2026/snr/usgs/usgs<doy>0.26.snr66.gz | Signal-to-noise ratio files — the intermediate step between raw RINEX and RH results
~/GNSS/v4.1/products/refl_code/2026/phase/usgs/ | Intermediate phase-data working files gnssrefl generates internally
~/GNSS/v4.1/products/refl_code/2026/rinex/usgs/ | gnssrefl's own internal copy of RINEX data used during analysis
~/GNSS/v4.1/products/refl_code/Files/usgs/ | Every plot and the final combined outputs live here — see full table below
~/GNSS/v4.1/products/refl_code/logs/usgs/2026/ | gnssrefl's own internal processing logs (separate from station_manager.out)
~/GNSS/v4.1/products/refl_code/input/usgs/usgs.json | The analysis strategy file — regenerated fresh every run from station.json
~/GNSS/v4.1/products/refl_code/orbits/ | Shared, reusable downloaded orbit files — not day-specific
~/GNSS/v4.1/products/refl_code/exe/ | Shared, reusable gnssrefl executables — not day-specific

Everything in ~/GNSS/v4.1/products/refl_code/Files/usgs/ (this is where your plots are):

Full path | What it shows
~/GNSS/v4.1/products/refl_code/Files/usgs/usgs_H0.png | The final water level plot — the one you look at most
~/GNSS/v4.1/products/refl_code/Files/usgs/usgs_spline_out.txt | The underlying evenly-sampled data behind usgs_H0.png — read by both comparison scripts
~/GNSS/v4.1/products/refl_code/Files/usgs/noaa_comparison.png | Output of compare_to_noaa.py
~/GNSS/v4.1/products/refl_code/Files/usgs/tide_model_comparison.png | Output of compare_to_tide_models.py
~/GNSS/v4.1/products/refl_code/Files/usgs/usgs_2026_combined.png | Intermediate subdaily diagnostic plot
~/GNSS/v4.1/products/refl_code/Files/usgs/usgs_2026_last.png | Intermediate subdaily diagnostic plot
~/GNSS/v4.1/products/refl_code/Files/usgs/usgs_2026_outliers.png | Intermediate subdaily diagnostic plot
~/GNSS/v4.1/products/refl_code/Files/usgs/usgs_2026_outliers_wrt_az.png | Intermediate subdaily diagnostic plot
~/GNSS/v4.1/products/refl_code/Files/usgs/usgs_2026_no_outliers_wrt_az.png | Intermediate subdaily diagnostic plot
~/GNSS/v4.1/products/refl_code/Files/usgs/usgs_rhdot1.png ... usgs_rhdot5.png | RHdot / inter-frequency bias correction diagnostic plots
~/GNSS/v4.1/products/refl_code/Files/usgs/outliers.txt, outliers.spline.txt, outliers.spline2.txt | Points flagged and removed as statistical outliers
~/GNSS/v4.1/products/refl_code/Files/usgs/usgs_2026_subdaily_all.txt | All observations before edit-out pass
~/GNSS/v4.1/products/refl_code/Files/usgs/usgs_2026_subdaily_edit.txt | Observations after edit-out pass, before RHdot correction

## 2.3 Source code: ~/GNSS/v4.1/station/

Full path | Purpose
~/GNSS/v4.1/station/station_manager.py | Top-level process — manages recording, triggers daily pipeline, exports to external storage once real results exist (or the retry window expires)
~/GNSS/v4.1/station/pipeline.py | RINEX conversion + GNSS-IR processing orchestration
~/GNSS/v4.1/station/rinex_processor.py | Converts raw .um980 to RINEX (.obs/.nav/.sbs)
~/GNSS/v4.1/station/gnssrefl_processor.py | Wraps gnssrefl's own Python API, reads all gnssrefl_* settings from station.json
~/GNSS/v4.1/station/receiver.py | Talks to the physical Unicore UM980 receiver
~/GNSS/v4.1/station/config.py | Loads station.json, computes all the paths in this document
~/GNSS/v4.1/station/database.py | All database read/write logic
~/GNSS/v4.1/station/start_station.sh | Starts the live recording process — does NOT need the venv activated
~/GNSS/v4.1/station/stop_station.sh | Stops the live recording process — does NOT need the venv activated

## 2.4 External storage (separate physical drive): /mnt/I2Rgus_Data/

Full path | What it is
/mnt/I2Rgus_Data/GPS_Data/Products/<YYYYMMDD>/ | Each day's full results get exported here once real GNSS-IR results exist for it (or the 3-day retry window expires), in a flattened structure (see below)
/mnt/I2Rgus_Data/ImageProducts/ | Camera images
/mnt/I2Rgus_Data/ImageProducts/latest/ | Latest single camera snapshots
/mnt/I2Rgus_Data/oldProducts/ | Staging folder used by ~/cleanup.sh before final jpg upload
/mnt/I2Rgus_Data/oldTiff/ | Staging folder used by ~/cleanup.sh before final tiff upload
/mnt/I2Rgus_Data/upload_count.txt | Shared daily image-upload counter (all 3 upload scripts add to this same number)

Inside each dated export folder (flattened — no more refl_code/ nesting):

/mnt/I2Rgus_Data/GPS_Data/Products/20260720/

├── results/usgs/<doy>.txt (and results/usgs/failQC/ subfolder)

├── snr/usgs/usgs<doy>0.26.snr66.gz

├── Files/usgs/ (all the plots, same list as section 2.2 above)

├── logs/usgs/2026/

├── input/usgs/

├── phase/usgs/, rinex/usgs/

├── orbits/, exe/ (shared resources)

└── other/ (anything gnssrefl added that isn't recognized)

So for example, on July 20's export, the main water level plot would be at:

/mnt/I2Rgus_Data/GPS_Data/Products/20260720/Files/usgs/usgs_H0.png

## 2.5 Camera scripts: ~/stationTools/ and ~/cleanup.sh

Full path | Purpose
~/stationTools/s3UpdateLatest.sh | Uploads latest/ camera images to S3
~/stationTools/s3UpdateProducts_athina.sh | Uploads products/ camera images to S3
~/cleanup.sh | Moves/uploads/cleans up camera images from local storage, contributes to the same upload counter

## 2.6 Miscellaneous

Full path | Purpose
~/process_gps_data.sh | Lives at your home directory (/home/argus_user/process_gps_data.sh), NOT inside GNSS/v4.1/ — the main one-command daily processing script
~/run_and_view.sh | Also at your home directory. The single-command wrapper: processes data, overlays tide models, and lands you in the plots folder
~/backup_before_deletion/ | Manual safety backups made before any destructive operation

# 3. Command Reference

Ordered from most to least frequently used in practice.

## 3.1 Process everything and view the result (the command you'll use most)

source ~/run_and_view.sh

Must be run with source (or the shorthand .), not ./. This is a real, unavoidable property of how shell processes work, not a style choice: a script run the normal way (./run_and_view.sh) executes as a separate child process, and a cd inside a child process can never reach back and change the directory of the shell that launched it. Sourcing runs the script directly in your own shell instead, so the final cd genuinely sticks around afterward.

This runs process_gps_data.sh, then overlays the result against marconi_tides_sherwood.xlsx, then leaves you standing in ~/GNSS/v4.1/products/refl_code/Files/usgs/ with a full directory listing — ready to immediately view or upload whatever plot you want, no separate cd needed.

## 3.2 Activate the Python environment

Needed before most other commands below, if not using 3.1 above.

cd ~/GNSS/v4.1

source gnssrefl_venv/bin/activate

Your prompt should now show (gnssrefl_venv) at the start of the line. If a command fails with ModuleNotFoundError, this step was skipped.

## 3.3 Process new data and generate all plots (without the tide overlay)

cd ~

source ~/GNSS/v4.1/gnssrefl_venv/bin/activate

./process_gps_data.sh

Runs the test suite, verifies layout, converts any new raw files, runs GNSS-IR analysis, and regenerates every plot in ~/GNSS/v4.1/products/refl_code/Files/usgs/. Very recent days (last 1-2) will normally fail with "orbit file does not exist" — this is expected; official orbit products take a day or two to publish.

## 3.4 Check the station is actually running and recording

ps aux | grep station_manager.py | grep -v grep

tail -10 ~/GNSS/v4.1/logs/station_manager.out

ls -la ~/GNSS/v4.1/raw/

Look for a real PID, a recent "Logging enabled" line, and a growing raw file for today's date in ~/GNSS/v4.1/raw/.

## 3.5 Compare against real scientific tide models

cd ~/GNSS/v4.1

source gnssrefl_venv/bin/activate

python3 compare_to_tide_models.py marconi_tides_sherwood.xlsx

Automatically finds and uses the most recently modified usgs_spline_out.txt, whether it's still sitting locally or has already been exported to external storage — no manual path editing needed. Saves to ~/GNSS/v4.1/products/refl_code/Files/usgs/tide_model_comparison.png.

## 3.6 Start / stop the station

~/GNSS/v4.1/station/stop_station.sh

Sends a graceful stop signal, waits for the current recording chunk to finish (can take several minutes).

~/GNSS/v4.1/station/start_station.sh

Starts it back up. Returns immediately.

Always restart after editing ~/GNSS/v4.1/station/resources/station.json — the live process only reads it at startup.

## 3.7 Compare against the calendar-style NOAA tide chart

cd ~/GNSS/v4.1

source gnssrefl_venv/bin/activate

python3 compare_to_noaa.py tides_1_2026-07.csv

Reads ~/GNSS/v4.1/tides_1_2026-07.csv (upload a new file with the same name to refresh it). Saves to ~/GNSS/v4.1/products/refl_code/Files/usgs/noaa_comparison.png.

## 3.8 Reconfigure the station (coordinates, tuning parameters, etc.)

cd ~/GNSS/v4.1

./setup_station.sh

Interactive wizard — walks through every setting, writes to ~/GNSS/v4.1/station/resources/station.json. Restart the station afterward (3.6) to load the changes.

## 3.9 Git backup

cd ~/GNSS/v4.1

git status

Review what's changed, then:

git add <specific files you want to commit>

git commit -m "Description of what changed and why"

git push

If push is rejected ("fetch first"):

git fetch origin

git diff --stat <last-known-commit> origin/clean-start

Review what changed remotely before merging:

git pull

git push

Verify success:

git rev-parse HEAD

git rev-parse origin/clean-start

These two hashes should match exactly.

## 3.10 Recover a day the automatic pipeline missed

cd ~/GNSS/v4.1

./recover_missing_days.sh 204 205 206 207

Use whenever a day's data seems to have gone missing (no results locally or in any export) despite the station having recorded that day — most likely because its orbit product wasn't published yet before the retry window expired. Finds that day's already-converted RINEX file wherever it landed in the external exports, regenerates its SNR file, and re-runs the real GNSS-IR analysis. Tells you plainly which days it could and couldn't recover. Run source ~/run_and_view.sh (3.1) afterward to fold the recovered day(s) into fresh plots.

## 3.11 Database maintenance — retiring a stale "file not found" error

If process_gps_data.sh keeps reporting an error for a raw file that's already been successfully processed and archived:

cd ~/GNSS/v4.1

python3 -c "

import sqlite3

conn = sqlite3.connect('database/station.db')

cursor = conn.execute(

'UPDATE processing_queue SET completed = 1, waiting = 0, '

'error_message = ? WHERE filename = ?',

('Retired: file intentionally no longer present locally', 'station_YYYYMMDD.um980'),

)

print('rows updated:', cursor.rowcount)

conn.commit()

conn.close()

"

Replace station_YYYYMMDD.um980 with the actual filename. This edits ~/GNSS/v4.1/database/station.db directly. This is cosmetic only — it doesn't affect any real data or plots.

## 3.12 Advanced diagnostics — quickLook (azimuth / quality-control investigation)

Requires the venv and three extra environment variables gnssrefl needs when called directly (normally set automatically by our own scripts):

cd ~/GNSS/v4.1

source gnssrefl_venv/bin/activate

export REFL_CODE=~/GNSS/v4.1/products/refl_code

export EXE=~/GNSS/v4.1/products/refl_code/exe

export ORBITS=~/GNSS/v4.1/products/refl_code/orbits

quickLook usgs 2026 <doy> -e1 5 -e2 15 -h1 -0.5 -h2 5.0 -ediff 1 -delTmax 40

Replace <doy> with a day-of-year number that has an SNR file available in ~/GNSS/v4.1/products/refl_code/2026/snr/usgs/. Produces a diagnostic plot showing which azimuth directions and satellites give good vs. bad retrievals — used to justify the azimuth mask setting.

## 3.13 Advanced — manually re-run GNSS-IR analysis for specific days

Same environment variables as 3.12 needed first.

gnssir usgs 2026 <doy_start> -doy_end <doy_end> -delTmax <minutes>

Example: gnssir usgs 2026 199 -doy_end 200 -delTmax 30 — re-runs the analysis for days 199-200 using SNR files that already exist locally in ~/GNSS/v4.1/products/refl_code/2026/snr/usgs/, overriding the arc-length setting for a one-off test. Overwrites the existing results files in ~/GNSS/v4.1/products/refl_code/2026/results/usgs/ for those days.

## 3.14 Run just the test suite

cd ~/GNSS/v4.1

source gnssrefl_venv/bin/activate

python -m unittest discover -s tests -v

Should end with "Ran 213 tests / OK" (or higher, if more have been added since). Test files live in ~/GNSS/v4.1/tests/.

## 3.15 Camera / image upload scripts

cd ~/stationTools

./s3UpdateLatest.sh

./s3UpdateProducts_athina.sh

cd ~

./cleanup.sh

These normally run automatically via cron — manual runs are only needed for troubleshooting.

# 4. Current Station Configuration (as of this writing)

Full path to the configuration file: ~/GNSS/v4.1/station/resources/station.json

Setting | Value | Why
Latitude / Longitude | 41.8928243333 / -69.9633227139 | Precise CSRS-PPP self-survey
Height (ellipsoidal) | -10.025 | Precise CSRS-PPP self-survey
Orthometric height | 18.665 | For real, absolute water level output
Elevation mask | 5° – 15° | Water-specific expert guidance, confirmed by two published case studies
Reflector height range | -0.5m – 5.0m | Wide margin to catch occasional large tides at this site
Maximum arc length | 40 minutes | Empirically tested — 20 min rejected nearly all data, 40 works well
Arc elevation-span tolerance | 1° | Recommended for this narrow an elevation mask
Direct-signal polynomial order | 2 | Fixes a recurring "poorly conditioned fit" warning
Azimuth mask | 100°-130°, 150°-215° | Confirmed via two independent days of quickLook diagnostics
Export retry window | 3 days | Gives a day's orbit product time to publish before giving up and exporting anyway

To see the live values at any time:

cat ~/GNSS/v4.1/station/resources/station.json

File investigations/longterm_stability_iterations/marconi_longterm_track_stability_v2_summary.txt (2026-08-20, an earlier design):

MARCONI LONG-TERM GNSS-R STABILITY V2
==============================================================================================================
Primary tide model: EOT20_heightm
Station H_ortho: 18.665 m
Azimuth cluster tolerance: 3.0 deg

GOOD TRACK CRITERIA
--------------------------------------------------------------------------------------------------------------
Minimum observations: 14
Minimum unique days: 14
Minimum tide correlation r: 0.90
Slope range: 0.85 to 1.15
Maximum unit-slope RMS: 30.0 cm
Maximum azimuth SD: 1.00 deg

DATUM TEST
--------------------------------------------------------------------------------------------------------------
Tested GNSS-R offset: +0.242 m
The datum offset is NOT used to select good tracks.

Total GPS L1 observations: 650
Total clustered tracks: 29
GOOD tracks: 21

GOOD TRACKS
--------------------------------------------------------------------------------------------------------------
 1. SAT=  9 rise=-1 N= 24 days=24 Az=  35.01±0.02 r=+0.9775 slope=+1.0310 rawRMS=27.01cm +24.2RMS=14.94cm improvement=+12.07cm
 2. SAT= 25 rise=-1 N= 22 days=22 Az=  47.62±0.02 r=+0.9761 slope=+0.8979 rawRMS=26.57cm +24.2RMS=19.23cm improvement=+7.34cm
 3. SAT= 29 rise= 1 N= 31 days=31 Az= 112.99±0.04 r=+0.9745 slope=+0.9519 rawRMS=32.24cm +24.2RMS=16.85cm improvement=+15.38cm
 4. SAT=  9 rise= 1 N= 23 days=23 Az= 124.43±0.07 r=+0.9742 slope=+1.0215 rawRMS=28.65cm +24.2RMS=14.05cm improvement=+14.60cm
 5. SAT= 29 rise=-1 N= 20 days=20 Az=  33.32±0.03 r=+0.9721 slope=+0.9976 rawRMS=26.63cm +24.2RMS=19.19cm improvement=+7.44cm
 6. SAT= 13 rise=-1 N= 14 days=14 Az=  38.85±0.07 r=+0.9684 slope=+0.8717 rawRMS=24.58cm +24.2RMS=21.07cm improvement=+3.51cm
 7. SAT= 27 rise=-1 N= 22 days=22 Az=  63.42±0.02 r=+0.9644 slope=+0.9208 rawRMS=36.10cm +24.2RMS=22.44cm improvement=+13.66cm
 8. SAT=  4 rise=-1 N= 22 days=22 Az=  30.52±0.01 r=+0.9629 slope=+0.9156 rawRMS=28.98cm +24.2RMS=19.02cm improvement=+9.96cm
 9. SAT=  8 rise=-1 N= 24 days=24 Az=  83.35±0.21 r=+0.9596 slope=+1.0171 rawRMS=37.31cm +24.2RMS=24.35cm improvement=+12.96cm
10. SAT= 12 rise=-1 N= 29 days=29 Az=  37.53±0.02 r=+0.9583 slope=+0.8733 rawRMS=25.53cm +24.2RMS=23.87cm improvement=+1.66cm
11. SAT= 28 rise=-1 N= 22 days=22 Az= 114.31±0.14 r=+0.9561 slope=+0.9674 rawRMS=30.89cm +24.2RMS=21.45cm improvement=+9.44cm
12. SAT= 30 rise= 1 N= 25 days=25 Az= 102.96±0.02 r=+0.9463 slope=+0.9421 rawRMS=32.21cm +24.2RMS=20.97cm improvement=+11.24cm
13. SAT=  5 rise=-1 N= 25 days=25 Az= 117.20±0.26 r=+0.9419 slope=+0.8847 rawRMS=37.98cm +24.2RMS=23.92cm improvement=+14.06cm
14. SAT= 20 rise=-1 N= 28 days=28 Az=  69.94±0.13 r=+0.9376 slope=+0.9273 rawRMS=41.05cm +24.2RMS=25.68cm improvement=+15.37cm
15. SAT=  4 rise= 1 N= 24 days=24 Az=  96.32±0.02 r=+0.9367 slope=+0.9034 rawRMS=34.08cm +24.2RMS=20.87cm improvement=+13.22cm
16. SAT=  6 rise=-1 N= 25 days=25 Az= 114.68±0.17 r=+0.9345 slope=+0.9793 rawRMS=39.50cm +24.2RMS=24.82cm improvement=+14.68cm
17. SAT= 31 rise=-1 N= 14 days=14 Az= 127.12±0.11 r=+0.9334 slope=+1.0884 rawRMS=37.88cm +24.2RMS=22.35cm improvement=+15.53cm
18. SAT=  2 rise=-1 N= 23 days=23 Az=  52.85±0.08 r=+0.9321 slope=+0.9867 rawRMS=35.30cm +24.2RMS=26.59cm improvement=+8.71cm
19. SAT= 16 rise=-1 N= 22 days=22 Az=  96.44±0.10 r=+0.9310 slope=+0.8633 rawRMS=40.09cm +24.2RMS=27.73cm improvement=+12.36cm
20. SAT= 30 rise=-1 N= 24 days=24 Az=  33.76±0.01 r=+0.9217 slope=+0.9210 rawRMS=41.63cm +24.2RMS=27.32cm improvement=+14.31cm
21. SAT= 21 rise=-1 N= 26 days=26 Az=  92.93±0.21 r=+0.9089 slope=+0.9246 rawRMS=44.78cm +24.2RMS=29.08cm improvement=+15.70cm

ALL CLUSTERED TRACKS, RANKED BY LONG-TERM SCORE
--------------------------------------------------------------------------------------------------------------
 1. SAT= 29 rise= 1 N= 31 days=31 Az= 112.99±0.04 r=+0.9745 slope=+0.9519 unitRMS=16.49cm GOOD=YES score=0.823
 2. SAT=  9 rise=-1 N= 24 days=24 Az=  35.01±0.02 r=+0.9775 slope=+1.0310 unitRMS=14.85cm GOOD=YES score=0.809
 3. SAT= 25 rise=-1 N= 22 days=22 Az=  47.62±0.02 r=+0.9761 slope=+0.8979 unitRMS=18.53cm GOOD=YES score=0.801
 4. SAT=  9 rise= 1 N= 23 days=23 Az= 124.43±0.07 r=+0.9742 slope=+1.0215 unitRMS=14.03cm GOOD=YES score=0.798
 5. SAT= 29 rise=-1 N= 20 days=20 Az=  33.32±0.03 r=+0.9721 slope=+0.9976 unitRMS=18.52cm GOOD=YES score=0.795
 6. SAT= 27 rise=-1 N= 22 days=22 Az=  63.42±0.02 r=+0.9644 slope=+0.9208 unitRMS=22.00cm GOOD=YES score=0.790
 7. SAT=  4 rise= 1 N= 24 days=24 Az=  96.32±0.02 r=+0.9367 slope=+0.9034 unitRMS=20.66cm GOOD=YES score=0.788
 8. SAT=  8 rise=-1 N= 24 days=24 Az=  83.35±0.21 r=+0.9596 slope=+1.0171 unitRMS=23.95cm GOOD=YES score=0.784
 9. SAT=  4 rise=-1 N= 22 days=22 Az=  30.52±0.01 r=+0.9629 slope=+0.9156 unitRMS=18.89cm GOOD=YES score=0.781
10. SAT= 30 rise= 1 N= 25 days=25 Az= 102.96±0.02 r=+0.9463 slope=+0.9421 unitRMS=20.96cm GOOD=YES score=0.774
11. SAT= 28 rise=-1 N= 22 days=22 Az= 114.31±0.14 r=+0.9561 slope=+0.9674 unitRMS=21.36cm GOOD=YES score=0.772
12. SAT= 20 rise=-1 N= 28 days=28 Az=  69.94±0.13 r=+0.9376 slope=+0.9273 unitRMS=24.02cm GOOD=YES score=0.770
13. SAT=  2 rise=-1 N= 23 days=23 Az=  52.85±0.08 r=+0.9321 slope=+0.9867 unitRMS=26.57cm GOOD=YES score=0.760
14. SAT= 13 rise=-1 N= 14 days=14 Az=  38.85±0.07 r=+0.9684 slope=+0.8717 unitRMS=19.15cm GOOD=YES score=0.753
15. SAT= 12 rise=-1 N= 29 days=29 Az=  37.53±0.02 r=+0.9583 slope=+0.8733 unitRMS=21.48cm GOOD=YES score=0.751
16. SAT=  6 rise=-1 N= 25 days=25 Az= 114.68±0.17 r=+0.9345 slope=+0.9793 unitRMS=23.69cm GOOD=YES score=0.741
17. SAT= 21 rise=-1 N= 26 days=26 Az=  92.93±0.21 r=+0.9089 slope=+0.9246 unitRMS=26.55cm GOOD=YES score=0.740
18. SAT=  1 rise=-1 N= 24 days=24 Az=  56.29±0.11 r=+0.8903 slope=+0.9349 unitRMS=29.04cm GOOD=NO score=0.738
19. SAT= 26 rise=-1 N= 21 days=21 Az=  90.79±0.21 r=+0.8957 slope=+0.9088 unitRMS=29.37cm GOOD=NO score=0.736
20. SAT= 16 rise=-1 N= 22 days=22 Az=  96.44±0.10 r=+0.9310 slope=+0.8633 unitRMS=27.23cm GOOD=YES score=0.736
21. SAT=  5 rise=-1 N= 25 days=25 Az= 117.20±0.26 r=+0.9419 slope=+0.8847 unitRMS=23.18cm GOOD=YES score=0.735
22. SAT= 15 rise=-1 N= 30 days=30 Az=  93.16±0.23 r=+0.8934 slope=+0.8980 unitRMS=30.68cm GOOD=NO score=0.722
23. SAT= 30 rise=-1 N= 24 days=24 Az=  33.76±0.01 r=+0.9217 slope=+0.9210 unitRMS=26.03cm GOOD=YES score=0.714
24. SAT= 24 rise=-1 N= 31 days=31 Az=  57.28±0.08 r=+0.9267 slope=+0.8372 unitRMS=25.05cm GOOD=NO score=0.712
25. SAT= 12 rise= 1 N=  5 days= 5 Az= 133.23±0.06 r=+0.9777 slope=+0.6363 unitRMS=8.48cm GOOD=NO score=0.696
26. SAT=  3 rise=-1 N= 22 days=22 Az=  37.15±0.07 r=+0.9231 slope=+0.8107 unitRMS=23.24cm GOOD=NO score=0.693
27. SAT= 31 rise=-1 N= 14 days=14 Az= 127.12±0.11 r=+0.9334 slope=+1.0884 unitRMS=21.15cm GOOD=YES score=0.678
28. SAT= 19 rise=-1 N= 14 days=14 Az= 148.96±0.13 r=+0.1945 slope=+0.0154 unitRMS=66.00cm GOOD=NO score=0.231
29. SAT= 25 rise= 1 N=  5 days= 5 Az= 157.86±0.02 r=+0.3233 slope=+0.0512 unitRMS=33.90cm GOOD=NO score=0.211

INTERPRETATION
--------------------------------------------------------------------------------------------------------------
The all-data plot is diagnostic only.
The primary scientific comparison is the GOOD TRACK plot.

Good-track selection is based on complete repeat tracks and does not
use the +0.242 m datum correction.
Therefore the +0.242 m comparison is an independent datum diagnostic.

If multiple independent GOOD tracks show substantially lower RMS after
+0.242 m, that is evidence that the GNSS-R solution has a common vertical
datum offset relative to the tide model.
If only one track improves, the apparent improvement may instead be track-
specific rather than a common datum correction.

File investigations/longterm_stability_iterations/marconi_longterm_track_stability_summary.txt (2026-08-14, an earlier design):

MARCONI LONG-TERM GNSS-R STABILITY / TIDE ANALYSIS
====================================================================================================
Primary tide model: EOT20_heightm
Station H_ortho: 18.665 m
GNSS-R result directory: products/refl_code/2026/results/usgs/ocean17_23_l1_e5_13
GNSS-R observations: 465
Observation interval: 2026-07-15 14:14:34.800000 through 2026-08-09 23:08:24

TOP LONG-TERM TRACKS
----------------------------------------------------------------------------------------------------
 1. SAT= 20 FREQ=  1 N= 20 days=20 Az= 69.88±0.10 r=+0.9267 slope=+0.9417 C=-0.320 unitRMS=24.82cm score=0.815
 2. SAT=  8 FREQ=  1 N= 17 days=17 Az= 83.44±0.12 r=+0.9438 slope=+1.0099 C=-0.308 unitRMS=25.33cm score=0.803
 3. SAT= 21 FREQ=  1 N= 19 days=19 Az= 92.84±0.17 r=+0.9219 slope=+0.9499 C=-0.326 unitRMS=25.55cm score=0.800
 4. SAT= 27 FREQ=  1 N= 15 days=15 Az= 63.43±0.01 r=+0.9560 slope=+0.9426 C=-0.288 unitRMS=22.17cm score=0.800
 5. SAT=  2 FREQ=  1 N= 17 days=17 Az= 52.89±0.05 r=+0.9070 slope=+0.9279 C=-0.252 unitRMS=27.86cm score=0.780
 6. SAT= 26 FREQ=  1 N= 14 days=14 Az= 90.71±0.16 r=+0.9113 slope=+0.9112 C=-0.251 unitRMS=26.23cm score=0.774
 7. SAT=  5 FREQ=  1 N= 17 days=17 Az=117.33±0.20 r=+0.9339 slope=+0.8960 C=-0.283 unitRMS=23.86cm score=0.772
 8. SAT= 16 FREQ=  1 N= 15 days=15 Az= 96.48±0.06 r=+0.9241 slope=+0.8777 C=-0.288 unitRMS=26.82cm score=0.766
 9. SAT=  1 FREQ=  1 N= 17 days=17 Az= 56.24±0.06 r=+0.8813 slope=+0.8612 C=-0.234 unitRMS=28.96cm score=0.764
10. SAT=  6 FREQ=  1 N= 18 days=18 Az=114.73±0.13 r=+0.9088 slope=+0.9347 C=-0.311 unitRMS=25.15cm score=0.761
11. SAT= 28 FREQ=  1 N= 15 days=15 Az=114.24±0.07 r=+0.9414 slope=+0.9322 C=-0.216 unitRMS=22.43cm score=0.759
12. SAT= 15 FREQ=  1 N= 22 days=22 Az= 93.26±0.19 r=+0.8681 slope=+0.8518 C=-0.274 unitRMS=31.86cm score=0.758
13. SAT= 24 FREQ=  1 N= 23 days=23 Az= 57.25±0.06 r=+0.9233 slope=+0.8009 C=-0.234 unitRMS=25.69cm score=0.752
14. SAT= 29 FREQ=  1 N= 36 days=23 Az= 84.23±38.27 r=+0.9694 slope=+0.9474 C=-0.233 unitRMS=18.05cm score=0.711
15. SAT=  9 FREQ=  1 N= 34 days=19 Az= 79.74±44.72 r=+0.9728 slope=+1.0134 C=-0.219 unitRMS=14.63cm score=0.709
16. SAT= 31 FREQ=  1 N=  8 days= 8 Az=127.05±0.06 r=+0.9078 slope=+0.9667 C=-0.288 unitRMS=20.79cm score=0.685
17. SAT=  4 FREQ=  1 N= 32 days=17 Az= 65.48±32.84 r=+0.9528 slope=+0.9131 C=-0.231 unitRMS=19.17cm score=0.683
18. SAT= 12 FREQ=  1 N= 25 days=21 Az= 52.85±35.09 r=+0.9697 slope=+0.8786 C=-0.183 unitRMS=19.20cm score=0.675
19. SAT= 30 FREQ=  1 N= 35 days=20 Az= 69.35±34.60 r=+0.9347 slope=+0.9460 C=-0.282 unitRMS=23.07cm score=0.672
20. SAT= 13 FREQ=  1 N= 15 days=12 Az= 58.49±39.30 r=+0.9348 slope=+0.9978 C=-0.072 unitRMS=27.53cm score=0.666

INTERPRETATION
The primary diagnostic water-level estimate is H_ortho - RH.
The unit-slope calibration constant C is computed separately
for each track as mean(GNSS_WL - primary tide).
This is a track-diagnostic statistic, not a production datum
calibration. Track rankings should be confirmed against physical
Fresnel/topobathy geometry before being called ocean tracks.

PLOTS
  marconi_all_gnssr_vs_tide_timeseries.png
  marconi_all_gnssr_vs_tide_scatter.png
  marconi_top_tracks_vs_tide.png
  marconi_top_track_residuals.png
  marconi_track_calibration_stability.png
  marconi_daily_population_vs_tide.png

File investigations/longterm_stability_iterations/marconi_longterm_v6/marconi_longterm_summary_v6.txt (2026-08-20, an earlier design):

MARCONI LONG-TERM GNSS-R / TIDE PIPELINE V6
================================================================================

Result directory: /home/argus_user/GNSS/v4.1/products/refl_code/2026/results/usgs/ocean17_23_l1_e5_13
Tide file: /home/argus_user/GNSS/v4.1/marconi_tides_sherwood.xlsx
Primary tide model: EOT20_heightm
Diagnostic offset: +0.242 m

GOOD criteria: N>=14, days>=14, r>=0.9, slope=0.85-1.15, RMS<=30.0 cm, az SD<=1.0 deg

GOOD: 0
NEAR-GOOD: 0
BAD: 34

RAW: N=0, mean bias=nan cm, mean abs deviation=nan cm, median abs deviation=nan cm, RMS=nan cm
+0.242 m: N=0, mean bias=nan cm, mean abs deviation=nan cm, median abs deviation=nan cm, RMS=nan cm

TRACKS
Track 01 SAT=3 rise=+1 BAD N=2 days=2 Az=137.78±0.00 r=1.0000 slope=1.3866 RMS=1665.65 cm fail=N,DAYS,SLOPE,RMS near=
Track 02 SAT=13 rise=+1 BAD N=3 days=3 Az=137.09±0.02 r=0.2169 slope=0.1160 RMS=1686.09 cm fail=N,DAYS,R,SLOPE,RMS near=
Track 03 SAT=19 rise=-1 BAD N=14 days=14 Az=148.96±0.09 r=-0.1945 slope=-0.0154 RMS=1807.64 cm fail=R,SLOPE,RMS near=
Track 04 SAT=25 rise=+1 BAD N=3 days=3 Az=157.85±0.01 r=-0.3233 slope=-0.0512 RMS=1892.83 cm fail=N,DAYS,R,SLOPE,RMS near=
Track 05 SAT=1 rise=-1 BAD N=20 days=20 Az=56.25±0.04 r=-0.8903 slope=-0.9349 RMS=1912.23 cm fail=R,SLOPE,RMS near=
Track 06 SAT=15 rise=-1 BAD N=24 days=24 Az=93.24±0.10 r=-0.8934 slope=-0.8980 RMS=1863.58 cm fail=R,SLOPE,RMS near=
Track 07 SAT=26 rise=-1 BAD N=17 days=17 Az=90.74±0.10 r=-0.8957 slope=-0.9088 RMS=1914.67 cm fail=R,SLOPE,RMS near=
Track 08 SAT=21 rise=-1 BAD N=21 days=21 Az=92.86±0.09 r=-0.9089 slope=-0.9246 RMS=1903.38 cm fail=R,SLOPE,RMS near=
Track 09 SAT=30 rise=-1 BAD N=19 days=19 Az=33.75±0.01 r=-0.9217 slope=-0.9210 RMS=1900.56 cm fail=R,SLOPE,RMS near=
Track 10 SAT=3 rise=-1 BAD N=19 days=19 Az=37.17±0.03 r=-0.9231 slope=-0.8107 RMS=1927.86 cm fail=R,SLOPE,RMS near=
Track 11 SAT=24 rise=-1 BAD N=25 days=25 Az=57.25±0.03 r=-0.9267 slope=-0.8372 RMS=1868.35 cm fail=R,SLOPE,RMS near=
Track 12 SAT=16 rise=-1 BAD N=18 days=18 Az=96.47±0.04 r=-0.9310 slope=-0.8633 RMS=1909.66 cm fail=R,SLOPE,RMS near=
Track 13 SAT=2 rise=-1 BAD N=20 days=20 Az=52.88±0.03 r=-0.9321 slope=-0.9867 RMS=1902.55 cm fail=R,SLOPE,RMS near=
Track 14 SAT=31 rise=-1 BAD N=11 days=11 Az=127.07±0.05 r=-0.9334 slope=-1.0884 RMS=1862.02 cm fail=N,DAYS,R,SLOPE,RMS near=
Track 15 SAT=6 rise=-1 BAD N=21 days=21 Az=114.72±0.07 r=-0.9345 slope=-0.9793 RMS=1932.06 cm fail=R,SLOPE,RMS near=
Track 16 SAT=4 rise=+1 BAD N=20 days=20 Az=96.33±0.01 r=-0.9367 slope=-0.9034 RMS=1924.87 cm fail=R,SLOPE,RMS near=
Track 17 SAT=20 rise=-1 BAD N=22 days=22 Az=69.89±0.06 r=-0.9376 slope=-0.9273 RMS=1871.68 cm fail=R,SLOPE,RMS near=
Track 18 SAT=5 rise=-1 BAD N=19 days=19 Az=117.30±0.10 r=-0.9419 slope=-0.8847 RMS=1858.24 cm fail=R,SLOPE,RMS near=
Track 19 SAT=30 rise=+1 BAD N=21 days=21 Az=102.97±0.01 r=-0.9463 slope=-0.9421 RMS=1931.36 cm fail=R,SLOPE,RMS near=
Track 20 SAT=28 rise=-1 BAD N=18 days=18 Az=114.25±0.05 r=-0.9561 slope=-0.9674 RMS=1899.16 cm fail=R,SLOPE,RMS near=
Track 21 SAT=12 rise=-1 BAD N=23 days=23 Az=37.54±0.01 r=-0.9583 slope=-0.8733 RMS=1893.90 cm fail=R,SLOPE,RMS near=
Track 22 SAT=8 rise=-1 BAD N=20 days=20 Az=83.42±0.09 r=-0.9596 slope=-1.0171 RMS=1898.58 cm fail=R,SLOPE,RMS near=
Track 23 SAT=4 rise=-1 BAD N=18 days=18 Az=30.52±0.01 r=-0.9629 slope=-0.9156 RMS=1950.41 cm fail=R,SLOPE,RMS near=
Track 24 SAT=27 rise=-1 BAD N=18 days=18 Az=63.42±0.01 r=-0.9644 slope=-0.9208 RMS=1908.07 cm fail=R,SLOPE,RMS near=
Track 25 SAT=13 rise=-1 BAD N=13 days=13 Az=38.84±0.03 r=-0.9684 slope=-0.8717 RMS=1879.54 cm fail=N,DAYS,R,SLOPE,RMS near=N,DAYS
Track 26 SAT=29 rise=-1 BAD N=16 days=16 Az=33.33±0.01 r=-0.9721 slope=-0.9976 RMS=1912.26 cm fail=R,SLOPE,RMS near=
Track 27 SAT=9 rise=+1 BAD N=20 days=20 Az=124.45±0.03 r=-0.9742 slope=-1.0215 RMS=1924.28 cm fail=R,SLOPE,RMS near=
Track 28 SAT=29 rise=+1 BAD N=25 days=25 Az=113.00±0.02 r=-0.9745 slope=-0.9519 RMS=1894.31 cm fail=R,SLOPE,RMS near=
Track 29 SAT=25 rise=-1 BAD N=18 days=18 Az=47.61±0.01 r=-0.9761 slope=-0.8979 RMS=1891.95 cm fail=R,SLOPE,RMS near=
Track 30 SAT=9 rise=-1 BAD N=20 days=20 Az=35.01±0.01 r=-0.9775 slope=-1.0310 RMS=1940.03 cm fail=R,SLOPE,RMS near=
Track 31 SAT=12 rise=+1 BAD N=5 days=5 Az=133.23±0.02 r=-0.9777 slope=-0.6363 RMS=1729.41 cm fail=N,DAYS,R,SLOPE,RMS near=
Track 32 SAT=11 rise=-1 BAD N=1 days=1 Az=133.44±0.00 r=nan slope=nan RMS=1657.65 cm fail=N,DAYS,R,SLOPE,RMS near=
Track 33 SAT=17 rise=-1 BAD N=1 days=1 Az=137.18±0.00 r=nan slope=nan RMS=1694.87 cm fail=N,DAYS,R,SLOPE,RMS near=
Track 34 SAT=32 rise=-1 BAD N=1 days=1 Az=147.73±0.00 r=nan slope=nan RMS=1907.31 cm fail=N,DAYS,R,SLOPE,RMS near=

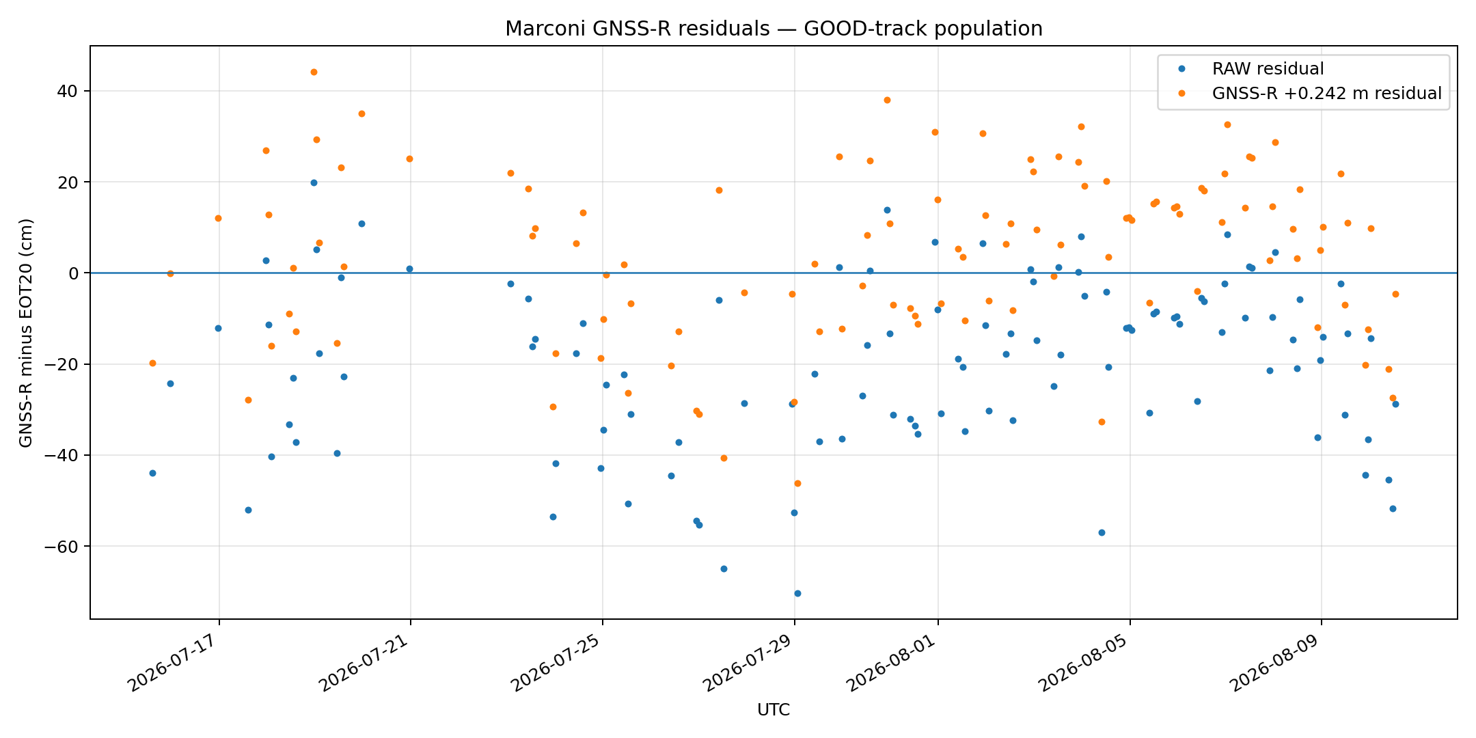
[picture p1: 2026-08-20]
investigations/longterm_stability_iterations/marconi_longterm_v8/plots/marconi_good_population_residuals_v8.png

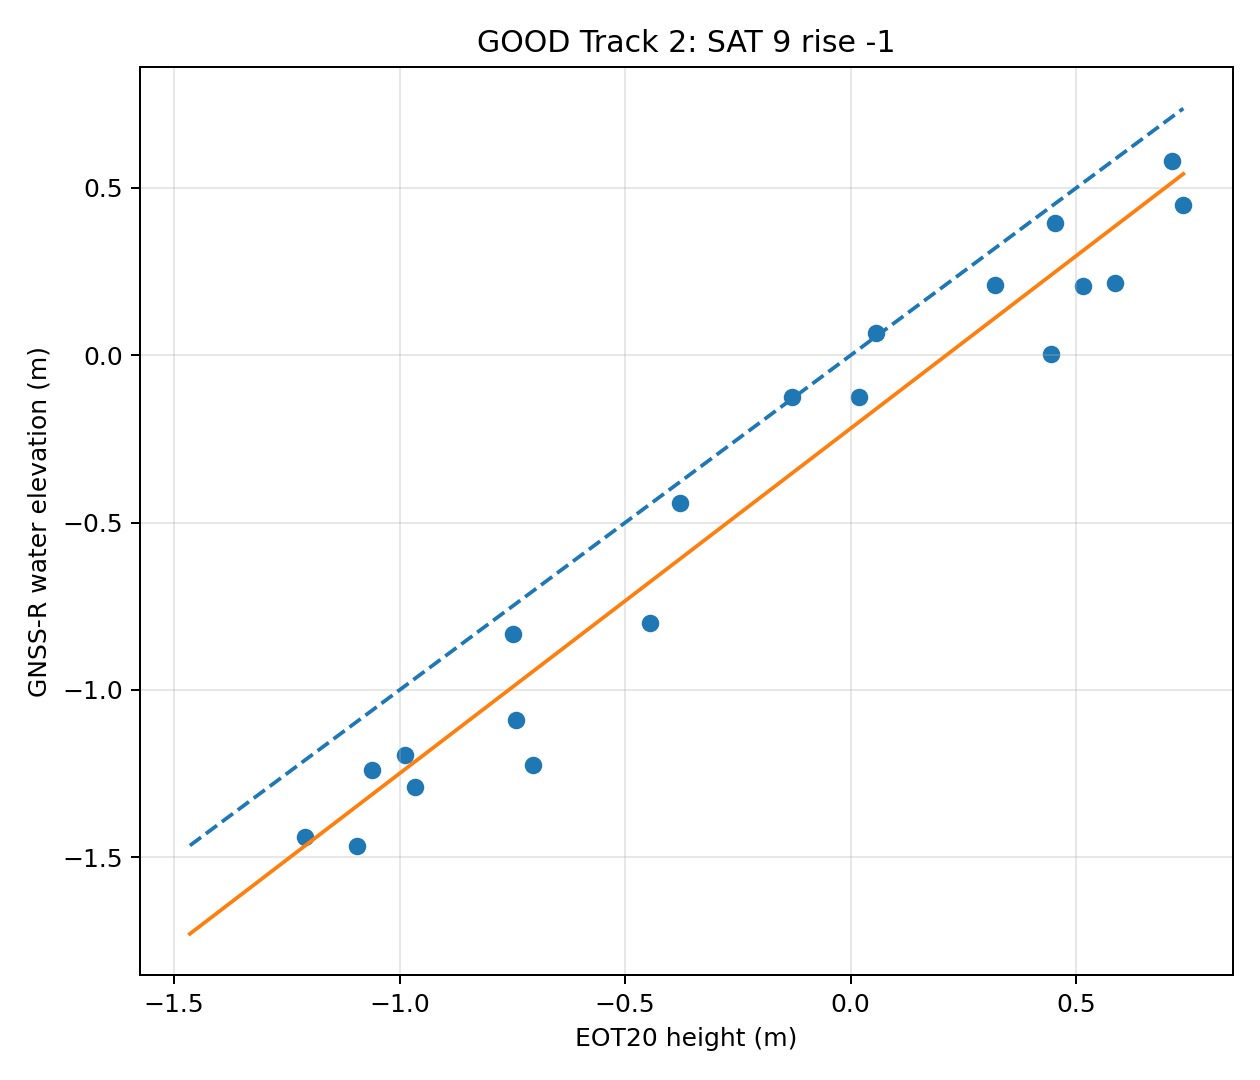
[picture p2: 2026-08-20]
investigations/longterm_stability_iterations/marconi_longterm_v8/plots/track_02_sat9_r-1.png

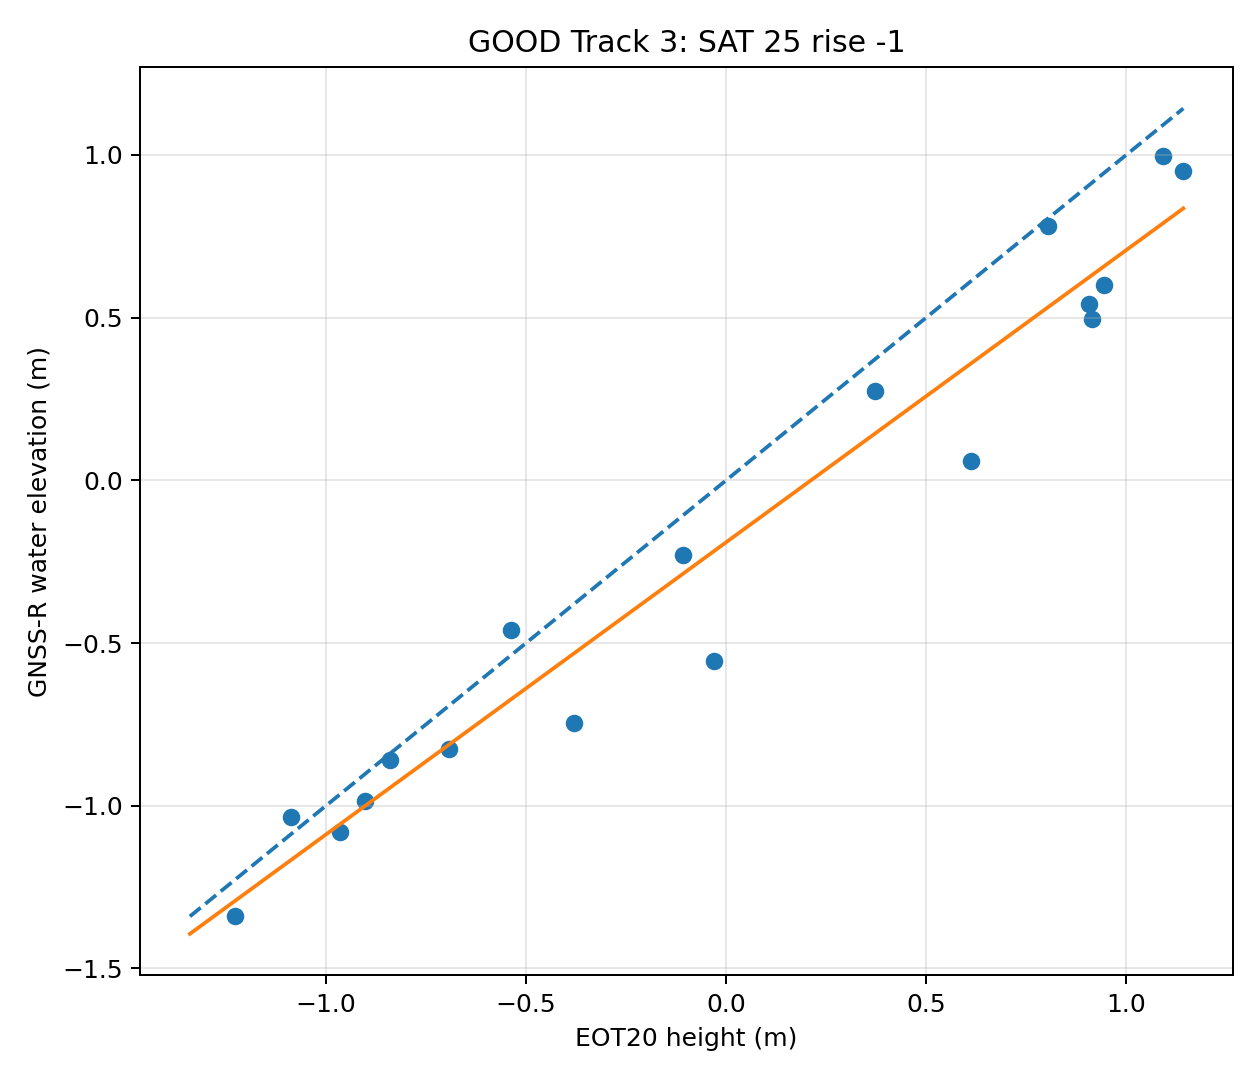
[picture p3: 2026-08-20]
investigations/longterm_stability_iterations/marconi_longterm_v8/plots/track_03_sat25_r-1.png

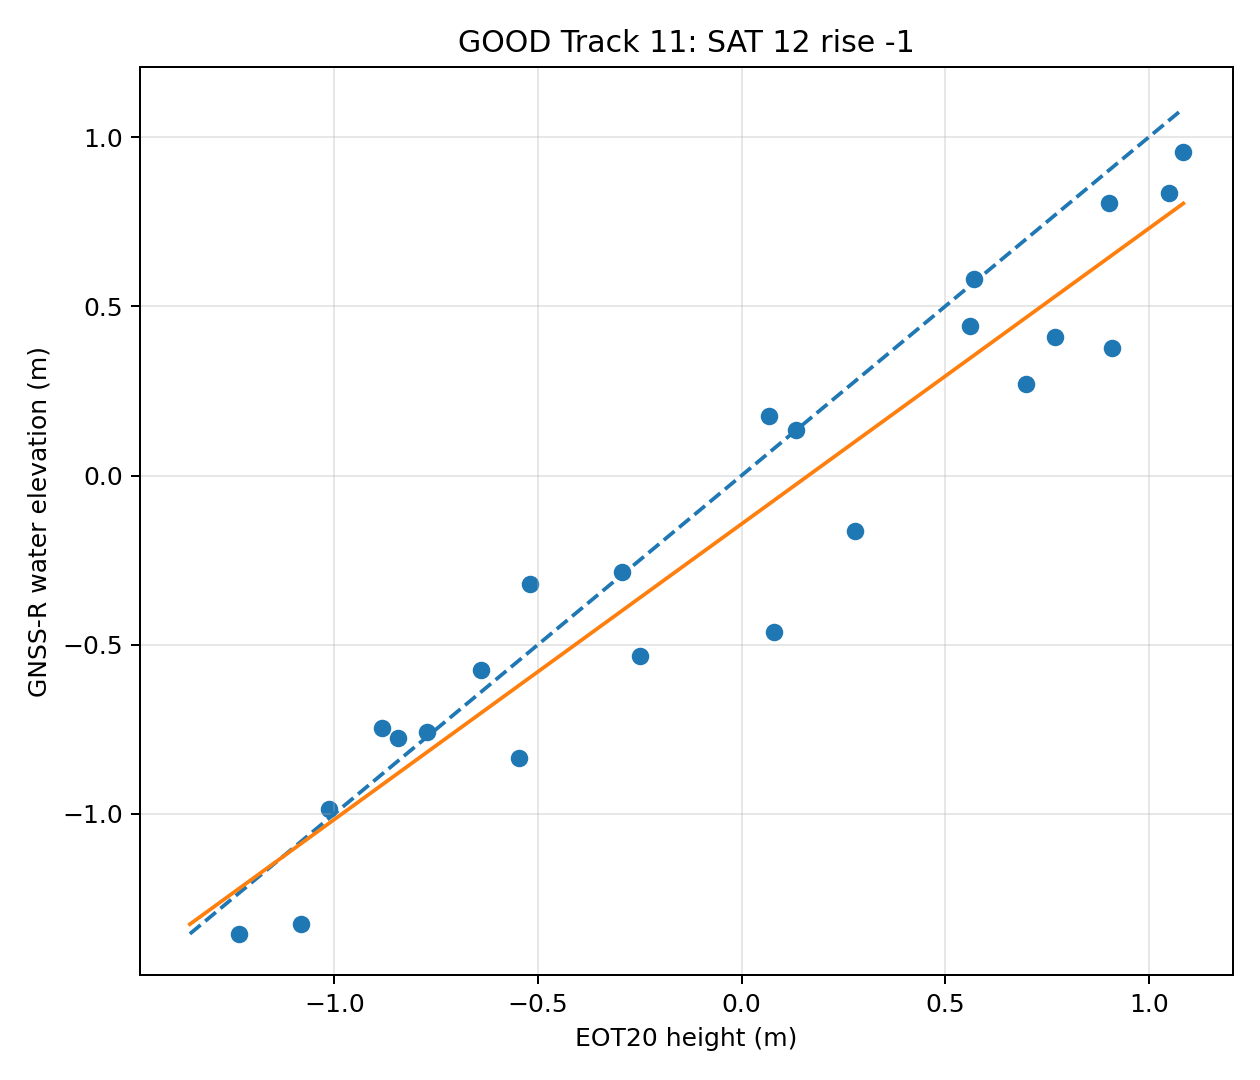
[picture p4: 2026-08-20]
investigations/longterm_stability_iterations/marconi_longterm_v8/plots/track_11_sat12_r-1.png

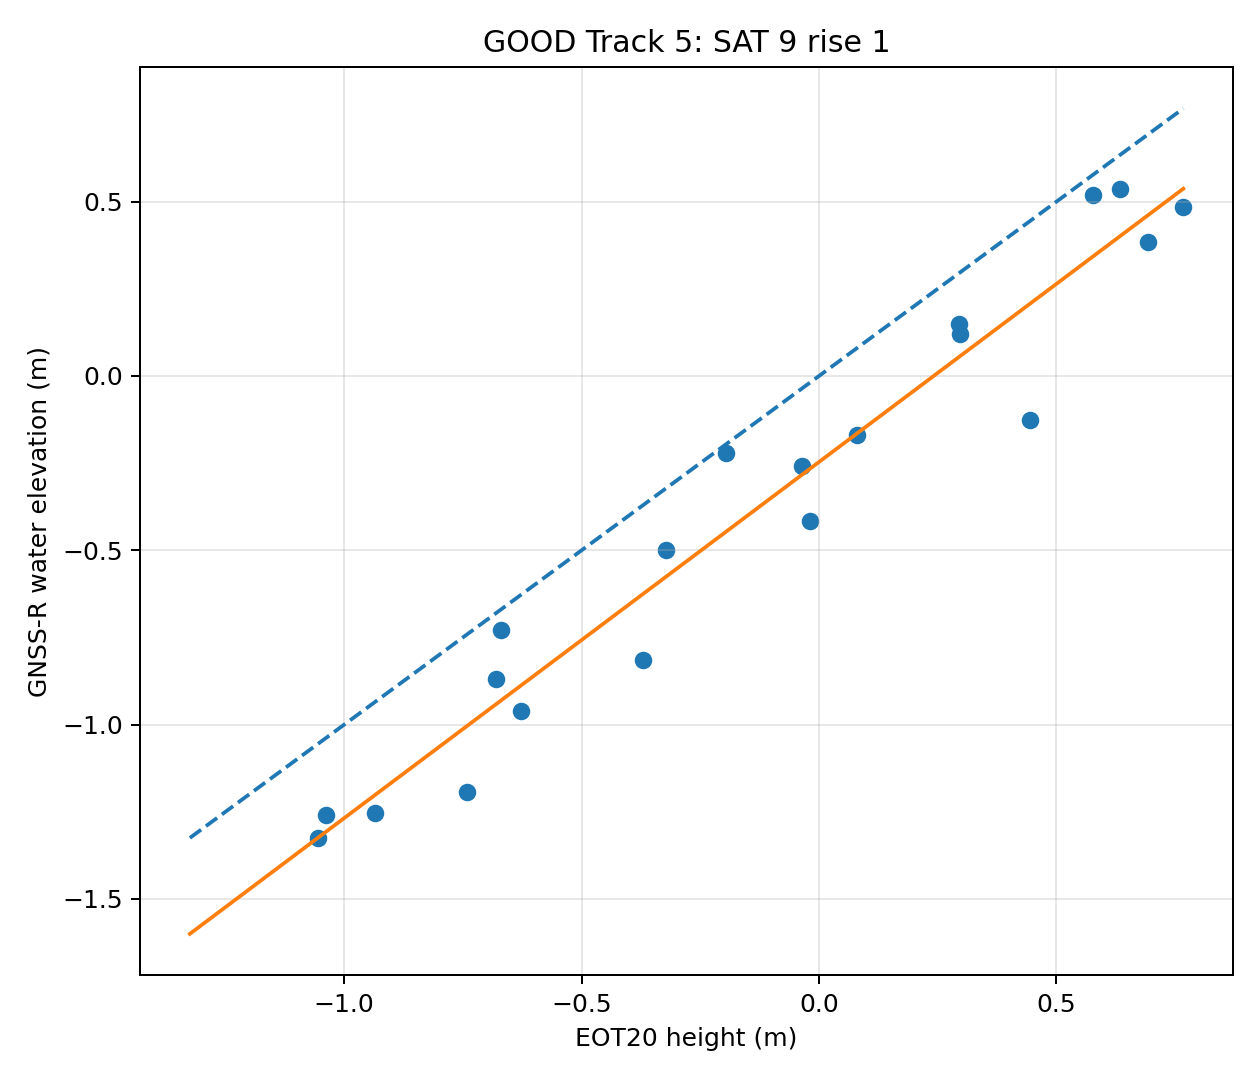
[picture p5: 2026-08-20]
investigations/longterm_stability_iterations/marconi_longterm_v8/plots/track_05_sat9_r1.png

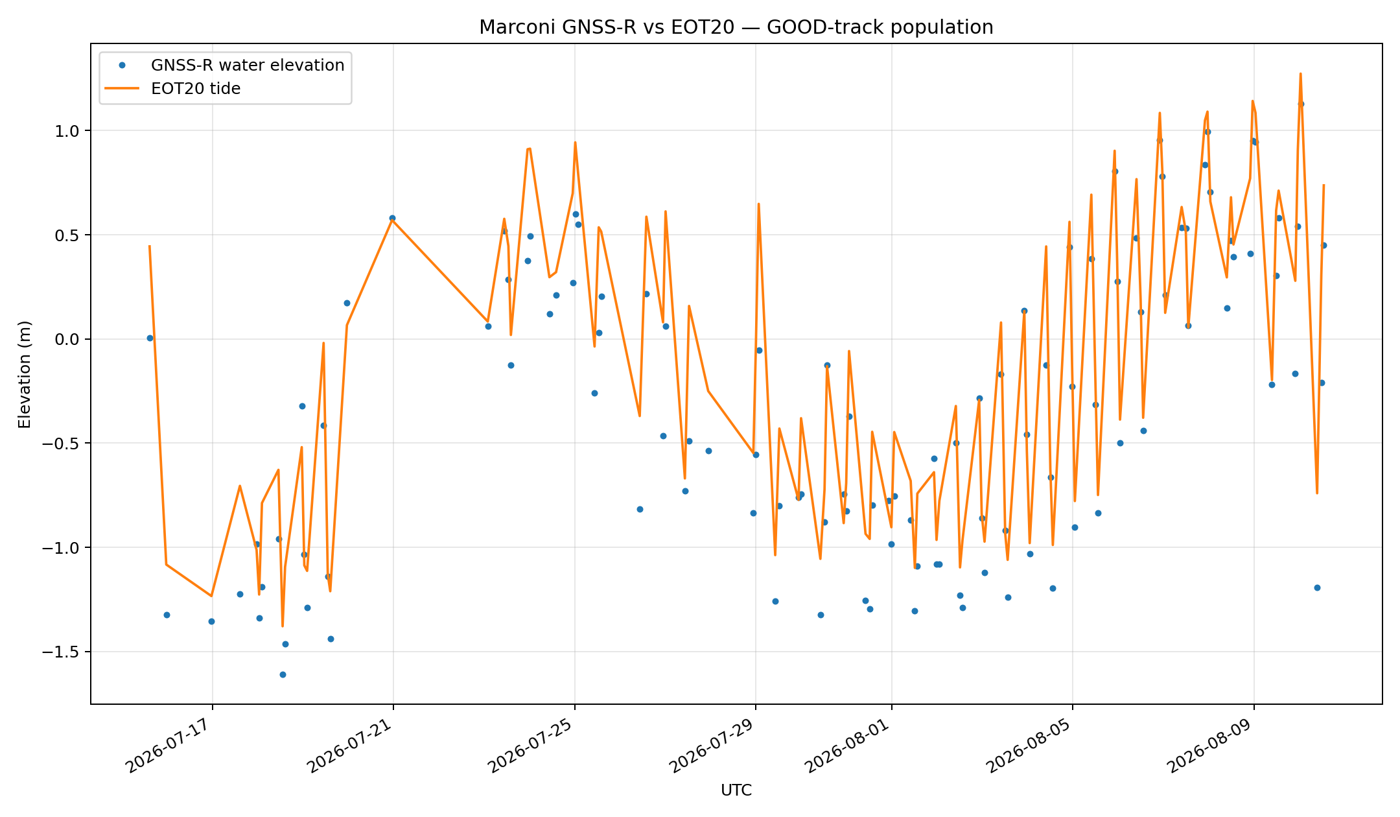
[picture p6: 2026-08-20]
investigations/longterm_stability_iterations/marconi_longterm_v8/plots/marconi_good_population_timeseries_v8.png

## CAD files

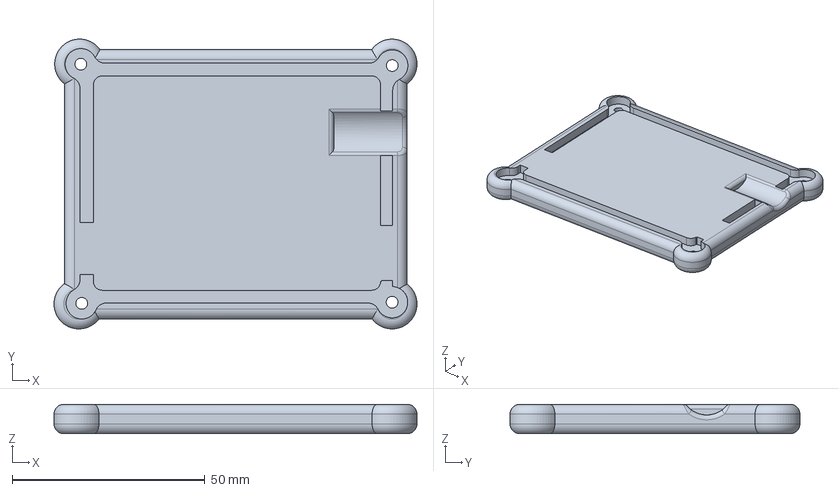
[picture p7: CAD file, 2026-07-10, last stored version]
3d enclosure models/ardusimple lid.stp
94.2 x 75.2 x 7.62 mm

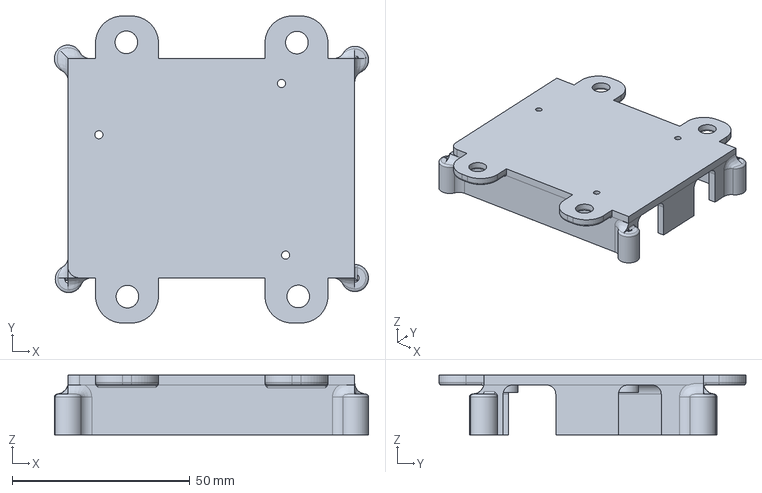
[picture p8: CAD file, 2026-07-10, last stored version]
Ardusimple box.stp
88.4 x 86.4 x 16.7 mm

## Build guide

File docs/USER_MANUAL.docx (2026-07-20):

# USGS GNSS Reference Station

A Complete Guide for Operators — No Prior Experience Required

Covers: daily operation, testing, the Python environment, and building a new station from a blank computer.

# Table of Contents

Chapter 1: Welcome

Chapter 2: Hardware and Materials Used

Chapter 3: A Few Concepts, Explained Simply

Chapter 4: A Tour of the Files and Folders

Chapter 5: The Python Virtual Environment

Chapter 6: Turning the System On

Chapter 7: How to Tell If It's Actually Working

Chapter 8: Testing the System

Chapter 9: Everyday Commands, All in One Place

Chapter 10: Setting Up a Brand New Machine

Chapter 11: Glossary of Terms

Chapter 12: When Something Goes Wrong

# Chapter 1: Welcome

This manual will teach you how to run, check on, and — if you ever need to — rebuild this GNSS reference station from scratch. It assumes you have never used this system before, and it does not assume you are a programmer. Every command you're asked to type is written out in full, and every step explains not just what to type but why.

Take your time. You cannot break anything by reading this manual or by typing the commands exactly as written. If a step doesn't go the way this manual describes, stop and re-read the relevant section — most problems come from a small typo or a missed earlier step, not something seriously wrong.

## What does this system actually do?

This station has a small GPS-like device called a UM980 receiver plugged into it. That device constantly listens to signals from satellites orbiting the earth. Most people think of GPS as just "finding your location" — and it does that — but this system uses the same signals for something else: measuring the height of the ground or water surface beneath the antenna, using a technique called GNSS-IR (GNSS Interferometric Reflectometry).

Here's the basic idea in plain terms: satellite signals don't just travel straight from the satellite to the antenna. Some of the signal bounces off the ground or water first, then reaches the antenna a fraction of a second later. When the direct signal and the bounced signal combine, they create a pattern that rises and falls in a very predictable way — and the speed of that rise-and-fall pattern tells you how far away the reflecting surface is. That's the whole trick. It's a bit like figuring out how deep a well is by timing an echo, except the "echo" is happening constantly, all day, using satellites that are already up there anyway.

To make that measurement, the system has to do four things, one after another, and it does all four completely on its own once it's running:

1. Record the raw data coming from the receiver, non-stop, all day.
2. Convert that raw data into a standard format called RINEX, which is the format GPS/GNSS scientists everywhere use to share data.
3. Feed that RINEX data into a piece of scientific software called gnssrefl, which does the actual reflectometry math.
4. Save the results, and keep a record in a small database of what happened along the way.

The rest of this manual walks through each of those pieces, how to check that they're working, and how to set the whole thing up again on a brand-new computer if you ever need to.

## A quick note on how this manual is written

Anything that looks like this is a command you type into the terminal, exactly as shown:

cd ~/GNSS/v4.1

Note: Boxes like this one point out something worth knowing, but not something you need to act on immediately.

Important: Boxes like this one flag something that really matters — usually because getting it wrong causes a confusing problem later.

# Chapter 2: Hardware and Materials Used

This chapter describes the physical equipment this station is built from -- what each piece is, its basic specifications, and the role it plays in the system as a whole. Software configuration for this hardware (serial port settings, antenna coordinates, and so on) is covered in later chapters; this chapter is purely about the physical parts.

## The computer

This station runs on an Intel NUC ("Next Unit of Computing") -- a small-form-factor computer -- installed as part of a larger coastal monitoring system called I2RGUS, built by Innovative Imaging & Research Corp. (I2R). I2RGUS is a camera-based system that captures, processes, and transfers coastal imaging measurements from remote shoreline locations; this NUC is shared between that imaging system and this GNSS station, which is why other, unrelated software (a camera control program, image-processing scripts) can be found alongside this project on the same machine.

More information about the I2RGUS platform itself is available at:

https://www.i2rcorp.com/field-solutions/i2rgus

The specific NUC runs Ubuntu 20.04.6 LTS, confirmed throughout this manual's installation chapter. Its role in this system is straightforward: it's the computer that runs every piece of software described in this manual -- receiving data from the GNSS receiver over USB, converting it, and running the analysis.

## The GNSS receiver board

The receiver itself is an ArduSimple SimpleRTK3B Budget board (part number AS-RTK3B-UM980-L125-NH), built around Unicore's UM980 GNSS receiver chip. This is the physical device referred to throughout this manual simply as "the receiver," connected to the NUC by USB.

### Basic specifications

- Chip: Unicore UM980
- Satellite systems received: BeiDou, Galileo, GLONASS, GPS, NavIC, QZSS, and SBAS -- this is a multi-constellation receiver, not GPS-only
- Function: navigation / GNSS evaluation board
- Antenna: not included on the board itself -- purchased and connected separately (see below)

### Its role in this system

This board is the actual source of every measurement this station makes. It listens continuously to signals from satellites across all the constellations listed above, and reports them over its USB connection in the UM980's own binary message format. Everything described in this manual downstream of "the receiver" -- raw recording, RINEX conversion, GNSS-IR processing -- exists to make sense of the data this one board produces.

## The antenna

The antenna is an ArduSimple budget survey-grade tripleband GNSS antenna (part number AS-ANT3B-BUDSUR-L1L2L5-25SMA), connected to the receiver board and mounted with a clear view of the sky.

### Basic specifications

- Applications / bands received: BeiDou, Galileo, GLONASS, GPS, QZSS
- Gain: 5 dBi
- Includes a built-in LNA (low-noise amplifier), needed to boost the very weak satellite signal before it travels down the cable to the receiver
- Cable: 2.5 m, terminated in a TNC connector
- Mounting: magnetic base
- Weather sealing: IP66 rated, suitable for permanent outdoor installation

### Its role in this system

The antenna is the only part of this station that needs a clear, unobstructed view of the sky -- everything else (the receiver board, the NUC, all the software in this manual) can sit indoors or in an enclosure. The antenna's physical stability matters directly to the quality of this station's results: Chapter 7 covers a tool, position_stability_check.py, built specifically to confirm the antenna is mounted securely and has a clean view of the sky before trusting a long recording.

## How the pieces fit together

In simple terms, signal flows physically like this: satellites overhead, down to the antenna (which also amplifies the signal), through 2.5 meters of cable to the receiver board, which decodes the raw satellite signals and sends them over USB to the NUC, where every piece of software described in the rest of this manual takes over.

# Chapter 3: A Few Concepts, Explained Simply

If you've used Windows or a Mac before but never a Linux computer like this one, a few terms in this manual might be unfamiliar. This chapter explains them once, in plain language, so the rest of the manual reads smoothly.

## The terminal

The terminal is a plain black (or dark) window where you type commands instead of clicking icons. It looks intimidating the first time you see it, but it works the same way every time: you type a line of text, press Enter, and the computer does exactly what you asked and shows you the result. There is no hidden trick to it — if a command in this manual doesn't do what's described, the most common reason is a small typo, so it's always worth double-checking exactly what you typed.

## Files and folders (directories)

A "directory" is simply the technical word for what you'd call a folder on Windows or a Mac. This manual uses the two words interchangeably. Directories are organized like a tree — folders inside folders — and you can move between them, list what's inside them, and so on, all from the terminal.

This whole system lives inside one main folder, referred to throughout this manual as the project folder. On this station, that folder is:

~/GNSS/v4.1

The squiggly symbol (~) is a shortcut that always means "your home folder" — you'll see it constantly.

## Python and "the virtual environment"

This entire system is written in a programming language called Python. You don't need to know how to write Python to operate this station — you just need to know how to turn the system on, check that it's healthy, and turn it off. But there's one Python-related idea you do need to understand, because you'll do it every single time you work with this system: activating the virtual environment.

Think of a virtual environment as a clean, self-contained toolbox that has exactly the right tools (software packages) this project needs, kept separate from anything else installed on the computer. Chapter 5 walks through this in full detail with real examples — for now, just know that "activating the environment" is always the very first thing you do before running any command related to this station.

## What "the receiver" means

Throughout this manual, "the receiver" refers to the physical UM980 device connected to the computer by a USB cable. It is the piece of hardware that actually listens to the satellites. The software talks to it, but the receiver itself is a separate little box, not part of the computer.

## Confirmed vs. untested

Everywhere in this manual, if a step has actually been performed and verified on this real station, it's presented as a normal instruction. In the few places where a procedure has not been tested on this particular system (mainly an alternative path in the installation chapter), it is clearly marked so you know the difference.

# Chapter 4: A Tour of the Files and Folders

This chapter is a guided walk through the project folder, so that when you see a file mentioned later in this manual, you already know roughly what it is and where it lives. You don't need to memorize this chapter — just skim it once, and come back to it as a reference.

## The main project folder

Everything lives under:

~/GNSS/v4.1

Inside it, you'll find a handful of folders. Here's what each one is for.

### station/ — the actual software

This folder contains all the Python program files that make the station run. You will rarely need to open or edit these files directly — they're mentioned here so that when this manual refers to "the receiver module" or similar, you know where it physically lives. A full description of each file is in Chapter 10 (as part of the from-scratch setup) and isn't required reading for day-to-day operation.

### raw/ — the recordings, in their original form

Every time the station records data from the receiver, it saves the untouched, original recording here first, before anything else happens to it. Files here have the extension .um980. Think of this as the "master tape" — nothing here is ever thrown away casually, and every other file the system produces is derived from something in this folder.

### rinex/ — the converted, standardized data

This is where the raw recordings get converted into RINEX format — the standard format used across the entire GPS/GNSS science community. Files here end in .obs (observation data) and .nav (navigation data).

### products/ — the scientific results

This is where the actual reflectometry results end up, buried a few folders deep (inside a subfolder called refl_code, which belongs to the gnssrefl software this station relies on). Chapter 7 shows you exactly which file to look at to see real results.

### database/ — the station's memory

A single file here, station.db, is a small database that keeps a record of every raw recording, every conversion, and every result the station has ever produced. You won't normally open this file directly, but tools described later in this manual read from it to tell you the station's status.

### logs/ — a written diary of what happened

Text files here record what the software was doing and when, which is invaluable if something ever needs troubleshooting. If the station is running continuously in the background (Chapter 6), its live activity is written here too.

### archive/ — completed work, filed away

Once a recording has been fully processed (converted and analyzed), the original raw file is moved here, out of the raw/ folder, to keep things tidy.

### gnssrefl_venv/ — the toolbox (virtual environment)

This folder holds the Python virtual environment mentioned in Chapter 3. You'll interact with it via one short command (Chapter 5) but never need to look inside it.

## A simple map

If you remember nothing else from this chapter, remember this flow — it's the same one described in Chapter 1, just showing where each stage lives on disk:

- A recording starts in raw/
- It gets converted, and the result appears in rinex/
- That gets analyzed, and the result appears in products/
- Everything that happened along the way is recorded in database/ and logs/

# Chapter 5: The Python Virtual Environment

This chapter explains, in full, the one habit you need to build before doing anything else with this station: activating the virtual environment. If you only remember one command from this entire manual, make it this one.

## Why this exists

This computer's operating system (Ubuntu Linux) comes with its own built-in version of Python already installed, used by the operating system itself for various background tasks. The scientific software this station depends on (called gnssrefl) needs a newer version of Python than the one built into this machine, and needs a specific set of additional software packages installed alongside it.

Rather than messing with the computer's built-in Python — which could break other things on the machine — this project keeps its own separate, self-contained copy of Python 3.10, along with every package it needs, inside one folder: gnssrefl_venv. This is what's called a virtual environment. It doesn't affect anything else on the computer, and nothing else on the computer affects it.

## Turning it on

Every time you open a new terminal window to work with this station, the very first thing you do is run this command:

source ~/GNSS/v4.1/gnssrefl_venv/bin/activate

That's it — one line. After you run it, look closely at your terminal prompt (the text just before where you type). You'll see it change to start with (gnssrefl_venv) in parentheses, like this:

(gnssrefl_venv) argus_user@standard-i2rgus-sn101123025-nuc10i3fnh:~$

Important: If you don't see (gnssrefl_venv) at the start of your prompt, the environment is not active, and commands involving Python or the station's software will either fail outright or — worse — silently run using the wrong version of Python. Whenever something unexpected happens, the very first thing to check is whether you see that prefix.

## Turning it off

You don't usually need to. It automatically stops applying once you close the terminal window. If you ever do want to manually step out of it while keeping the window open, the command is simply:

deactivate

Your prompt will lose the (gnssrefl_venv) prefix, confirming you're back to the plain system Python.

## A simple way to think about it

Imagine this computer has two completely separate Python "kitchens." One is the operating system's own kitchen, always present, used for basic housekeeping tasks. The other is a specially stocked kitchen built just for this project, with every ingredient (software package) this project needs, and nothing it doesn't. The activate command is simply you walking into the project's kitchen. Every recipe (command) in the rest of this manual assumes you're standing in that kitchen — so it's always step one.

# Chapter 6: Turning the System On

This chapter shows you how to start the station recording and processing data continuously, on its own, with no further attention needed. This is the normal, everyday way this station runs.

## How the station stays running automatically

This station uses a scheduling tool built into Linux called cron to keep itself running. In simple terms: a small startup script is set to run automatically whenever the computer boots up, and a second check runs every five minutes to make sure the station is still alive — restarting it automatically if it ever isn't. You do not need to understand cron in detail to operate the station day to day; this section is here so you know it exists and isn't a mystery if you ever see it mentioned.

## Starting the station by hand

Most of the time, the station starts itself automatically. But if you ever need to start it manually — for instance, right after doing maintenance — here is exactly how.

First, activate the environment (Chapter 5):

source ~/GNSS/v4.1/gnssrefl_venv/bin/activate

Then run the start script:

~/GNSS/v4.1/station/start_station.sh

This command does not print anything if it works, and that's normal — it starts the station quietly in the background and hands your terminal back to you immediately.

Note: This command is safe to run even if the station is already running. It checks first, and does nothing if it finds the station is already active. You cannot accidentally start two copies running at once by running this command more than once.

## Stopping the station

If you ever need to stop the station — for maintenance, to move the equipment, or any other reason — use:

~/GNSS/v4.1/station/stop_station.sh

Here is the one thing about stopping the station that surprises people the first time: it does not stop instantly. The station is always in the middle of recording a block of data (normally ten minutes long), and it finishes that block cleanly before actually shutting down, rather than cutting it off abruptly and losing data. This means the stop command can take up to several minutes to finish. You'll see a message confirming when it has actually stopped:

Stopped cleanly after 465s.

Important: This waiting behavior is intentional, confirmed working, and exists to protect your data. Do not interrupt the stop command or forcibly kill the process out of impatience — just let it finish.

# Chapter 7: How to Tell If It's Actually Working

A system that runs quietly in the background is only useful if you can easily check on it. This chapter covers three levels of checking: is the software running at all, is it actually recording real data, and is it producing real scientific results.

## Level 1: Is the program even running?

Every time the station starts, it writes its own process ID number (a unique number the operating system assigns to every running program) to a small file. You can use that number to check whether it's genuinely alive:

ps -p $(cat ~/GNSS/v4.1/logs/station_manager.pid) -o pid,etime,cmd

If the station is running, you'll see a line showing its process ID, how long it's been running (ELAPSED), and the command it's running. If it's not running, you'll see an empty result (just the column headers, no data line beneath them).

## Level 2: Watch it working, live

To watch exactly what the station is doing right now, in real time:

tail -f ~/GNSS/v4.1/logs/station_manager.out

This will show you a continuous stream of activity — connecting to the receiver, recording a block of data, finishing that block, starting the next one, and so on. Press Ctrl+C to stop watching (this does not stop the station itself — it only stops the live display in your terminal).

A healthy station shows lines like these, roughly every ten minutes:

... Recording chunk #1 for 600s (append=False) -> .../station_20260709.um980

... Connected to /dev/USB_GPS

... Logging enabled: [...]

... Chunk complete: 343933 byte(s), 2409 message(s)

If you see repeated error messages instead of steady progress like this, see Chapter 12 (Troubleshooting).

## Level 3: Are there real scientific results?

The most meaningful check is whether the station is actually producing results, not just recording. Real results — reflector height measurements — appear in a text file inside the products folder, organized by year and by day-of-year (a number from 1 to 365 counting the day within the current year).

For example, to check results for day-of-year 190 of 2026:

cat ~/GNSS/v4.1/products/refl_code/2026/results/usgs/190.txt

A file with real results looks like a table of numbers, with a few lines starting with a percent sign (%) at the top explaining what each column means, followed by many rows of actual measurements. If the file exists but has no data rows below the % lines, or doesn't exist yet, that generally just means there isn't yet enough continuous data for that day for the software to find a usable measurement — reflectometry needs several continuous hours of data to work, not just a few minutes. This is expected, not a malfunction, for a day that's only just begun or was interrupted.

## A quick daily-check routine

A reasonable habit is to run these three checks, in order, whenever you want quick peace of mind that everything is healthy:

1. Check the process is running (Level 1, above).
2. Watch a few minutes of live activity (Level 2) and confirm you see steady "Chunk complete" messages with no repeated errors.
3. Spot-check that yesterday's results file exists and has data rows in it (Level 3).

## A bonus tool: checking antenna stability before a long recording

Before committing to a long recording (several hours, or overnight), it's worth spending ten minutes confirming the antenna and receiver are behaving in a healthy, stable way. A tool built for exactly this, position_stability_check.py, repeatedly asks the receiver for its current position and reports how much that position is wandering -- both side-to-side (horizontal) and up-and-down (vertical) -- once every minute, for ten minutes.

Run it like this (after activating the environment, Chapter 5):

cd ~/GNSS/v4.1/station

python3 position_stability_check.py

It prints a line every minute, looking something like this:

[ 1.0 min] samples= 30 horizontal dev: 0.0607 m vertical dev: 0.0209 m

[ 2.0 min] samples= 59 horizontal dev: 0.1774 m vertical dev: 0.2398 m

[ 10.0 min] samples=293 horizontal dev: 0.1945 m vertical dev: 0.4192 m

What these numbers mean: this station does not use survey-grade corrections, so its position naturally wanders a small amount from one moment to the next, even sitting perfectly still -- that wandering is exactly what this tool measures. As more samples accumulate over the ten minutes, the numbers should settle down and stop growing, rather than keep climbing. A healthy result generally settles somewhere in the range of a few tens of centimeters horizontally, with the vertical number typically two to three times larger than the horizontal one -- that difference is normal and expected, not a problem, because satellites are only ever visible from above the horizon, which makes vertical measurements inherently less precise than horizontal ones for any GNSS receiver.

Note: This tool doesn't need to record any data or run gnssrefl -- it only asks the receiver for its position over and over, so it's completely safe to run at any time, even while the station is already recording in the background.

Important: If the numbers keep climbing instead of settling down, or come back far larger than described above (multiple meters, not centimeters), that's worth investigating before starting a long recording -- possible causes include a loose antenna cable connection, the antenna having a poor view of the sky (nearby buildings or trees blocking satellites), or reflective surfaces nearby interfering with the signal.

# Chapter 8: Testing the System

Separate from actually recording real data, this station comes with its own built-in self-check — a large collection of automated tests that verify every piece of the software behaves correctly. Running these tests does not touch the real receiver or produce real data; it's purely a software health check, and it's completely safe to run at any time, even while the station is recording.

## Why this matters

Software test suites like this one exist to catch mistakes before they cause real problems. Every time this station's software is updated, running the full test suite is the fastest way to confirm nothing was accidentally broken.

## Running the tests

First, activate the environment (Chapter 5), then move into the main project folder and run:

source ~/GNSS/v4.1/gnssrefl_venv/bin/activate

cd ~/GNSS/v4.1

python -m unittest discover -s tests -v

This will print a long list of individual test names, each ending in "ok" if that particular check passed. This is normal and expected — there are over 160 individual checks, so the output is long. What matters is the very last few lines:

Ran 163 tests in 12.123s

OK

Seeing OK at the end means every single check passed. That single word is what you're really looking for — you can safely ignore the long scroll of output above it on a normal, successful run.

Important: If you instead see the word FAILED at the end (often followed by a count, like FAILED (failures=1)), something is genuinely wrong and needs attention before you trust the system's results. Scroll up from the FAILED line to find a line starting with FAIL: or ERROR:, which names the specific check that failed — that name, and the paragraph of text just beneath it, is exactly what to share with whoever is helping you fix it.

## Checking the overall project layout

A second, faster check confirms that every expected file is present and looks the way it should — useful right after setting up a new machine, or after transferring files:

python check_layout.py

A healthy result ends with:

============================================================

ALL CHECKS PASSED

============================================================

# Chapter 9: Everyday Commands, All in One Place

This chapter is a quick-lookup reference. Once you're familiar with the rest of this manual, this is the page you'll likely return to most often. Every command below assumes the virtual environment is already active (Chapter 5) unless noted otherwise.

## Starting and stopping

Command | What it does
~/GNSS/v4.1/station/start_station.sh | Start the station (safe to run even if already running)
~/GNSS/v4.1/station/stop_station.sh | Stop the station gracefully (waits for the current recording block to finish)

## Checking on the station

Command | What it does
ps -p $(cat ~/GNSS/v4.1/logs/station_manager.pid) -o pid,etime,cmd | Confirm the station process is alive, and how long it's been running
tail -f ~/GNSS/v4.1/logs/station_manager.out | Watch live activity (Ctrl+C to stop watching)
crontab -l | List the scheduled tasks that keep the station running automatically
python3 position_stability_check.py | 10-minute antenna stability check (run from station/, Chapter 7)

## Testing

Command | What it does
python -m unittest discover -s tests -v | Run the full automated test suite
python check_layout.py | Verify all expected files are present and correctly sized

## Configuration

Command | What it does
~/GNSS/v4.1/setup_station.sh | Interactive wizard for station identity, coordinates, and advanced gnssrefl fine-tuning (Chapter 10)

## Looking at results

Command | What it does
cat ~/GNSS/v4.1/products/refl_code/2026/results/usgs/<day>.txt | View a specific day's reflectometry results (replace <day> with a 3-digit day-of-year, and 2026 with the correct year)
ls -la ~/GNSS/v4.1/raw/ | List recent raw recordings
ls -la ~/GNSS/v4.1/rinex/ | List converted RINEX files

## The environment

Command | What it does
source ~/GNSS/v4.1/gnssrefl_venv/bin/activate | Turn on the project's Python environment (do this first, every time)
deactivate | Turn it back off (rarely needed)

## Working with the code repository (git)

Command | What it does
cd ~/GNSS && git pull | Download the latest version of the software
git status | See what's changed locally, if anything

# Chapter 10: Setting Up a Brand New Machine

This chapter is for the day you need to build this entire station again from a blank computer — a replacement NUC, a rebuild after a hard drive failure, or a second station somewhere else. It assumes even less prior knowledge than the rest of this manual, and walks through every step in order, start to finish.

This is the longest chapter in the manual. That's normal — setting up a system like this genuinely involves many small pieces. Go through it in order, and don't skip ahead.

Note: Every step in this chapter except two (clearly marked) has actually been performed and confirmed working while building this exact station. Where a step hasn't been personally verified, this manual says so plainly rather than guessing.

## Step 1: Confirm what operating system you have

This station runs a version of Linux called Ubuntu. Before doing anything else, confirm exactly which version is on the new machine:

lsb_release -a

This station was built on Ubuntu 20.04.6 LTS (with the code name "focal"). If your new machine shows the same thing, you can follow this chapter exactly as written.

## Step 2: Decide how to get a new-enough Python

The scientific software this station depends on (called gnssrefl) requires a newer version of Python than the one that comes built into Ubuntu 20.04. There are two ways to solve this. This manual documents the one that was actually used and confirmed working; the other is included for completeness but was not tested on this station.

### Recommended path (confirmed working): install a second, separate Python alongside the existing one

This does not touch or replace the operating system's own built-in Python at all — it simply adds a second one, kept completely separate, just for this project. This is the approach the rest of this chapter follows.

### Alternative path (not tested on this station): upgrade Ubuntu itself to a newer version

Some people prefer to upgrade the whole operating system instead, which would come with a newer Python already built in. This is a bigger, riskier change — it affects everything on the computer, not just this one project — and it was not the approach used here, so this manual can't walk you through it step by step with the same confidence. If you choose this route, here is the general process:

- Check your current version first, so you know your starting point: lsb_release -a
- Make sure everything currently installed is fully up to date before upgrading:

sudo apt update && sudo apt full-upgrade -y

- Reboot, in case the update above installed a new kernel: sudo reboot
- Run the actual release upgrade tool:

sudo do-release-upgrade

This will ask several questions along the way (keep your current configuration when prompted, unless you have a specific reason not to) and will itself prompt you to reboot again once finished.

- After rebooting, confirm the new version: lsb_release -a

Important: This alternative path is included for completeness only. It was not exercised while building this station, and every later step in this chapter assumes you instead followed the recommended path below.

## Step 3: Install the tools needed to build Python from source

These are small utility packages the computer needs in order to build Python itself in the next step. Copy and paste this whole block as one command:

sudo apt install -y build-essential zlib1g-dev libncurses5-dev libgdbm-dev \

libnss3-dev libssl-dev libreadline-dev libffi-dev libsqlite3-dev wget libbz2-dev \

liblzma-dev

You'll be asked to confirm partway through — type y and press Enter if prompted.

## Step 4: Build and install Python 3.10

Download the Python source code:

cd ~

wget https://www.python.org/ftp/python/3.10.13/Python-3.10.13.tgz

tar -xzf Python-3.10.13.tgz

cd Python-3.10.13

Prepare the build:

./configure --enable-optimizations --prefix=/usr/local

This will print a lot of text and take a minute or two. Once it finishes, actually build Python:

make -j$(nproc)

Note: This step is slow — it can take anywhere from about 15 minutes to over an hour, depending on the computer. This is completely normal. Let it run; you'll know it's done when your terminal prompt returns and you can type again.

Once that finishes, install it — notice this uses altinstall, not install, which is important:

sudo make altinstall

Important: Do not substitute plain 'make install' for 'make altinstall'. The 'alt' version installs this new Python as a second, separate copy (python3.10) without disturbing the computer's original built-in Python (python3). Using the wrong command here could interfere with other software on the computer that depends on the original Python.

Confirm both versions of Python now exist side by side:

python3 --version

python3.10 --version

You should see two different version numbers — the original (3.8-something) and the new one (3.10.13). Both existing at once, side by side, is exactly the intended result.

## Step 5: Install and configure git

git is the tool used to download ("clone") this project's software, and to pull down updates later without transferring files by hand. Install it if it isn't already present:

sudo apt install -y git

git likes to know a name and email address, so it can record who made each change. This matters even on a station only you will ever touch -- set it once:

git config --global user.name "Your Name"

git config --global user.email "you@example.com"

Confirm it installed correctly:

git --version

## Step 6: Download the software

This station is built from two separate pieces of software, kept in two separate online repositories: this project's own code, and gnssrefl (the third-party GNSS-IR analysis package it relies on). Downloading a repository this way is called "cloning" it.

### This project's own code

This is the actual station software -- the receiver control, RINEX conversion, database, and everything else described throughout this manual.

cd ~

git clone -b clean-start https://github.com/emarsjanik/GPS_code.git GNSS

Note: The -b clean-start part matters -- it tells git to download the clean-start branch specifically, which is the real, current, working version of this project. Leaving this out would download a different, older branch instead.

This creates a new folder called GNSS in your home folder. (If your project needs to end up at a different path than ~/GNSS/v4.1, you may need to adjust folder names to match -- but on a station set up to mirror this one, no further adjustment should be needed.)

In the future, whenever the software has been updated and you want the latest version, this is the only command you need:

cd ~/GNSS

git pull

### gnssrefl's own source code

This station's actual, working installation of gnssrefl comes from a simple pip install (Step 9) -- you do not need this clone for the system to function. It's worth having a copy of gnssrefl's own source on hand anyway, for reference: reading its real documentation offline, looking up a command's exact options, or understanding exactly what a piece of its analysis code does.

cd ~/software

git clone https://github.com/kristinemlarson/gnssrefl.git

(If you don't have a ~/software folder yet, this is the same folder Step 8 uses for RTKLIB -- create it first with mkdir -p ~/software.)

## Step 7: Build and install convbin (RTKLIB)

convbin is a small, separate program that this station uses to convert the receiver's raw recordings into the standard RINEX format (Chapter 4). It comes from a larger, well-known GNSS software package called RTKLIB, and it needs to be built from its source code rather than installed as a simple package.

Download RTKLIB's source code. A dedicated folder for third-party software (kept separate from this project's own folder) is a sensible place for it:

mkdir -p ~/software

cd ~/software

git clone https://github.com/rtklibexplorer/RTKLIB.git

Build convbin specifically (RTKLIB contains several programs; this station only needs this one):

cd ~/software/RTKLIB/app/consapp/convbin/gcc

make

This produces a compiled program in that same folder, also named convbin. Install it so the rest of the system can find it simply by typing its name, without needing the full folder path:

sudo cp convbin /usr/local/bin/convbin

Confirm it's now available:

which convbin

Note: This should print /usr/local/bin/convbin. Keep the ~/software/RTKLIB folder around afterward, rather than deleting it -- it's the source this program was built from, and having it on hand makes it easy to rebuild if this station is ever moved to a new machine, or if convbin needs to be reinstalled for any reason.

## Step 8: Create the project's own Python "toolbox" (virtual environment)

This is the one-time setup for the virtual environment described in Chapter 5. Move into the project folder and create it, using the new Python 3.10 you just installed:

cd ~/GNSS/v4.1

python3.10 -m venv gnssrefl_venv

Turn it on (same command you'll use every day afterward — see Chapter 5):

source gnssrefl_venv/bin/activate

Make sure the toolbox's own installer program is up to date:

pip install --upgrade pip

## Step 9: Install the required Python packages

With the environment active (you should see (gnssrefl_venv) in your prompt), install the two things this project needs:

pip install pyserial

pip install gnssrefl

The second command will take a little while and download quite a lot of supporting software along with it — that's normal and expected, gnssrefl relies on several other well-established scientific Python packages internally.

## Step 10: Fill in the station's configuration

Rather than hand-editing the settings file directly, this project includes an interactive setup wizard that walks through every setting -- station identity, receiver details, coordinates, and a range of advanced gnssrefl fine-tuning options -- and writes them all into the right place for you.

~/GNSS/v4.1/setup_station.sh

It will ask a series of questions, showing a default in [brackets] wherever one exists -- just press Enter to accept it. Three questions (latitude, longitude, and antenna height) are genuinely required and it will keep asking until you provide a real, plain decimal number for each -- not degrees/minutes/seconds notation.

Important: Enter coordinates as plain decimal degrees (e.g. 41.8928), not degrees/minutes/seconds (e.g. 41 53'34"). If you only have DMS-format coordinates from another source, convert them to decimal first -- plenty of free online converters can do this.

Everything past the basic identity questions is optional -- advanced settings like the elevation angle mask, reflector height search range, and azimuth mask are only worth setting if you have a specific reason to (an obstructed view, an unusually tall or short site). Leaving them blank is completely normal and lets gnssrefl use its own sensible defaults.

Once finished, it writes everything to station/resources/station.json directly -- there's no separate save step needed.

## Step 11: Refine your coordinates with Precise Point Positioning (PPP)

This step is important for high-quality data. The coordinates entered in Step 10 are only as accurate as their original source -- often a rough map estimate or a consumer GPS reading, good enough to get started but not precise enough for real GNSS-IR analysis. Once the station has recorded at least one full day of real data, you can use that data itself to get a genuinely precise position, accurate to the centimeter level.

This uses CSRS-PPP, a free, authoritative Precise Point Positioning service run by Natural Resources Canada -- despite the name, it works worldwide, not just in Canada, and is widely used and trusted in real published GNSS research for exactly this purpose.

### 1. Pick a good, complete day of raw data

A full, gap-free day gives the best result. Check the archive/ folder for a day that recorded continuously:

find ~/GNSS/v4.1 -name "station_YYYYMMDD.um980"

(replace YYYYMMDD with a real date once you've picked one -- recent days are usually still in raw/, older ones move to archive/ automatically)

### 2. Convert it to RINEX at 30-second intervals

CSRS-PPP (like most PPP services) expects 30-second data, not this station's normal 1-second recording -- faster sampling doesn't improve the result and produces an unnecessarily large upload. Convert directly from the raw file with a 30-second interval:

mkdir -p ~/ppp_upload

cd ~/ppp_upload

/usr/local/bin/convbin -r nov -v 3.05 -os -ti 30 -o ppp_upload.obs -n ppp_upload.nav ~/GNSS/v4.1/archive/station_YYYYMMDD.um980

This produces a much smaller .obs file (roughly 10-15 MB for a full day, versus several hundred MB at full 1-second resolution) -- only the .obs file is needed for the next step.

### 3. Submit it to CSRS-PPP

Sign up for a free account, then submit your file:

https://webapp.geod.nrcan.gc.ca/geod/tools-outils/ppp.php

- Enter your email address for the results
- Select Static as the processing mode (this station doesn't move)
- Select ITRF as the reference frame -- the globally standard choice, and what gnssrefl expects
- Upload ppp_upload.obs and submit

Note: Results typically arrive by email anywhere from about an hour up to 36 hours later, depending on how quickly official precise orbit products publish for that date. This is normal -- there's nothing to troubleshoot while waiting.

### 4. Update station.json with the precise result

The email contains a report with an "Estimated Position" -- latitude, longitude, and ellipsoidal height, along with an estimated accuracy (sigma). Update these three values in station/resources/station.json (either by re-running setup_station.sh, or editing the file directly), replacing the original estimate with this precise, self-derived position.

## Step 12: Confirm everything is correctly in place

Run the two checks from Chapter 8:

python check_layout.py

python -m unittest discover -s tests -v

Both should finish cleanly (ALL CHECKS PASSED, and OK at the end of the test run) before you move on.

## Step 13: Set up automatic startup

Make the start/stop scripts runnable:

chmod +x ~/GNSS/v4.1/station/start_station.sh

chmod +x ~/GNSS/v4.1/station/stop_station.sh

Then open the scheduling editor:

crontab -e

Add these two lines at the bottom of the file (adjust the username in the path if it isn't argus_user on the new machine), then save and exit:

@reboot /home/argus_user/GNSS/v4.1/station/start_station.sh

*/5 * * * * /home/argus_user/GNSS/v4.1/station/start_station.sh

The station will now start automatically the next time the computer boots, and will check itself every five minutes, restarting on its own if it's ever found not running.

To start it right now, without waiting for a reboot, simply run the start command directly (Chapter 6):

~/GNSS/v4.1/station/start_station.sh

Congratulations — at this point, you have a fully working station, built from nothing. Return to Chapter 7 to confirm it's healthy.

# Chapter 11: Glossary of Terms

Plain-language definitions of terms used throughout this manual, gathered in one place.

### GNSS

Global Navigation Satellite System — the general term covering GPS and similar satellite systems from other countries (Russia's GLONASS, Europe's Galileo, China's BeiDou, Japan's QZSS). This station listens to all of them, not just American GPS satellites.

### GNSS-IR / reflectometry

The technique this station exists to perform: using the way satellite signals bounce off a nearby surface to measure the height of that surface, as explained in Chapter 1.

### Receiver

The physical UM980 device connected to the computer that listens to satellite signals.

### RINEX

A standard file format used across the GNSS science community for sharing satellite observation data. This station converts its raw recordings into this format as a middle step.

### gnssrefl

The scientific software package (written by Dr. Kristine Larson) that actually performs the reflectometry calculations, once this station has produced RINEX data for it to work with.

### Virtual environment

A self-contained copy of Python and its required add-on packages, kept separate from the rest of the computer. See Chapter 5.

### Terminal

The text-based window used to type commands, instead of clicking icons. See Chapter 3.

### Directory

Another word for "folder."

### cron / crontab

A built-in Linux tool for scheduling tasks to run automatically, used here to start the station on boot and check on it every few minutes.

### Process ID (PID)

A unique number the operating system assigns to every currently-running program, used to check whether a specific program (like this station) is actually still running.

### git / repository

git is a tool for tracking and downloading versions of software. A repository (or "repo") is the project's home online, from which the software can be freshly downloaded ("cloned") onto any computer.

### Day-of-year (DOY)

A number from 1 to 365 (or 366 in a leap year) counting which day of the current year it is — January 1st is day 1, December 31st is day 365. Results files are organized by this number because that's the convention the GNSS science community uses.

# Chapter 12: When Something Goes Wrong

This chapter covers situations that look alarming the first time you see them but usually have a simple explanation.

## "My terminal prompt doesn't show (gnssrefl_venv)"

You haven't activated the virtual environment yet, or it stopped being active (this happens automatically if you close and reopen your terminal). Fix: run the activate command from Chapter 5 again.

## "The test suite says FAILED instead of OK"

Scroll up in the output to find a line starting with FAIL: or ERROR: — that names the specific problem. This is worth investigating before trusting the station's results, but it does not mean the whole system is broken; usually one specific piece needs attention.

## "stop_station.sh seems stuck / isn't finishing"

This is very likely not stuck — as explained in Chapter 6, a graceful stop waits for the current recording block to finish, which can take several minutes (up to the length of one recording block, currently ten minutes). Give it time before assuming something is wrong.

## "A results file for today has no data in it, or doesn't exist yet"

Reflectometry needs several continuous hours of data to find a usable measurement. This is completely expected for the current day before enough hours have passed, or after a station restart part-way through a day. Check yesterday's results file instead to confirm the system is genuinely working.

## "I see repeated error messages in the live log"

A single occasional error mentioning a retry is generally not alarming — the software is built to retry automatically and keep going. Many repeated errors in a row, especially ones mentioning the receiver or the serial port, are worth investigating — check the physical USB connection to the receiver first, since a loose cable is the most common real-world cause.

## "check_layout.py reports a problem"

This usually means a file is missing, empty, or an unexpectedly different size than expected — most often because a file transfer didn't fully complete. Re-transfer the specific file it flags and run the check again.

## When to ask for help

If a problem doesn't match anything in this chapter, the most useful things to gather before asking for help are: the exact command you ran, the complete output it produced (not just a summary), and — if relevant — the contents of the relevant log file from the logs/ folder.

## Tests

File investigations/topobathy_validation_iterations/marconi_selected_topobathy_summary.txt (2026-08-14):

MARCONI TRUE TOPOBATHY / FRESNEL VALIDATION
================================================================================================

Topobathy: 2021022FA_Marconi_topobathy_1m.tif
CRS: EPSG:6348
Station latitude: 41.8928243333
Station longitude: -69.9633227139
H_ortho: 18.665 m
MSL NAVD88 hypothesis: -0.242 m
Primary tide model: EOT20_heightm

The tide-predicted water surface is:
    water_surface_NAVD88 = EOT20 + MSL_NAVD88

The equivalent tide-predicted reflector height is:
    RH_predicted = H_ortho - water_surface_NAVD88

SELECTED TRACK GEOMETRY
------------------------------------------------------------------------------------------------
PRN 29 RISING  Az= 113.01 N=23 r=+0.9765 RMS=16.5 cm bias=-3.2 cm obs9wet=0.972 pred5wet=nan pred9wet=0.976 pred13wet=0.319 class=WATER_DOMINANT
PRN 13 SETTING Az=  38.84 N=12 r=+0.9719 RMS=19.5 cm bias=+4.0 cm obs9wet=0.907 pred5wet=1.000 pred9wet=0.915 pred13wet=0.109 class=WATER_DOMINANT
PRN  4 RISING  Az=  96.33 N=17 r=+0.9459 RMS=19.7 cm bias=+0.2 cm obs9wet=1.000 pred5wet=1.000 pred9wet=1.000 pred13wet=0.677 class=WATER_DOMINANT
PRN  9 RISING  Az= 124.46 N=17 r=+0.9759 RMS=13.7 cm bias=+2.1 cm obs9wet=nan pred5wet=nan pred9wet=nan pred13wet=0.000 class=OUTSIDE_RASTER

INTERPRETATION
------------------------------------------------------------------------------------------------
This is a physical footprint validation, not a statistical
tide-validation score.

A track is not called confirmed ocean solely because the
GNSS-R time series follows EOT20. The independent topobathy
footprint must also be water-dominated.

The current +0.242 m datum hypothesis is used only to derive
the tide-predicted NAVD88 water surface for geometry.

The raster is EPSG:6348 and is sampled at its 1-m cell centers.

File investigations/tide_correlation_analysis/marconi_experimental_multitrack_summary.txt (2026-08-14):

MARCONI EXPERIMENTAL MULTI-TRACK GNSS-R WATER-LEVEL PRODUCT
================================================================================================

GNSS-R configuration:
  GPS L1 only
  RH 17-23 m
  elevation 5-13 deg

H_ortho = 18.665 m
datum test = +0.242 m

TRACK SELECTION CRITERIA:
  N >= 10
  |corrected median offset| <= 0.050 m
  corrected RMS <= 0.200 m
  tide r >= 0.93

Total repeated tracks considered: 26
Selected tracks: 4
Selected observations: 69
Daily product days: 23

SELECTED TRACKS
------------------------------------------------------------------------------------------------
PRN 29 RISING  Az= 113.01 N=23 days=23 r=+0.9765 slope=+0.9455 median=-3.18 cm RMS=16.50 cm
PRN  9 RISING  Az= 124.46 N=17 days=17 r=+0.9759 slope=+0.9973 median=+2.05 cm RMS=13.69 cm
PRN 13 SETTING Az=  38.84 N=12 days=12 r=+0.9719 slope=+0.8876 median=+3.97 cm RMS=19.47 cm
PRN  4 RISING  Az=  96.33 N=17 days=17 r=+0.9459 slope=+0.8927 median=+0.16 cm RMS=19.67 cm

OTHER REPEATED TRACKS
------------------------------------------------------------------------------------------------
PRN 25 SETTING Az=  47.61 N=16 r=+0.9706 corr_median=+11.5 cm corr_RMS=18.8 cm
PRN  9 SETTING Az=  35.02 N=17 r=+0.9699 corr_median=+6.2 cm corr_RMS=15.9 cm
PRN 12 SETTING Az=  37.54 N=21 r=+0.9657 corr_median=+12.1 cm corr_RMS=21.7 cm
PRN  4 SETTING Az=  30.52 N=15 r=+0.9596 corr_median=+8.1 cm corr_RMS=18.7 cm
PRN 29 SETTING Az=  33.33 N=13 r=+0.9591 corr_median=+10.1 cm corr_RMS=20.6 cm
PRN 27 SETTING Az=  63.43 N=15 r=+0.9560 corr_median=-6.7 cm corr_RMS=22.6 cm
PRN  3 SETTING Az=  37.18 N=16 r=+0.9439 corr_median=+7.0 cm corr_RMS=22.6 cm
PRN  8 SETTING Az=  83.44 N=17 r=+0.9438 corr_median=-10.1 cm corr_RMS=26.2 cm
PRN 28 SETTING Az= 114.24 N=15 r=+0.9414 corr_median=+12.8 cm corr_RMS=22.6 cm
PRN 30 RISING  Az= 102.97 N=18 r=+0.9354 corr_median=-8.3 cm corr_RMS=21.3 cm
PRN  5 SETTING Az= 117.33 N=17 r=+0.9339 corr_median=-7.5 cm corr_RMS=24.2 cm
PRN 30 SETTING Az=  33.75 N=17 r=+0.9335 corr_median=+4.7 cm corr_RMS=25.5 cm
PRN 20 SETTING Az=  69.88 N=20 r=+0.9267 corr_median=-12.0 cm corr_RMS=26.0 cm
PRN 16 SETTING Az=  96.48 N=15 r=+0.9241 corr_median=-1.3 cm corr_RMS=27.2 cm
PRN 24 SETTING Az=  57.25 N=23 r=+0.9233 corr_median=-5.4 cm corr_RMS=25.7 cm
PRN 21 SETTING Az=  92.84 N=19 r=+0.9219 corr_median=-0.2 cm corr_RMS=26.9 cm
PRN 26 SETTING Az=  90.71 N=14 r=+0.9113 corr_median=+9.0 cm corr_RMS=26.2 cm
PRN  6 SETTING Az= 114.73 N=18 r=+0.9088 corr_median=-4.4 cm corr_RMS=26.1 cm
PRN  2 SETTING Az=  52.89 N=17 r=+0.9070 corr_median=-15.2 cm corr_RMS=27.9 cm
PRN  1 SETTING Az=  56.24 N=17 r=+0.8813 corr_median=-2.7 cm corr_RMS=29.0 cm
PRN 15 SETTING Az=  93.26 N=22 r=+0.8681 corr_median=-7.5 cm corr_RMS=32.0 cm
PRN 19 SETTING Az= 148.97 N=12 r=+0.0016 corr_median=+159.1 cm corr_RMS=158.6 cm

SCIENTIFIC STATUS
------------------------------------------------------------------------------------------------
This is an experimental multi-track GNSS-R product.
The +0.242 m vertical transformation is retained as an external
datum hypothesis test and is not fitted to this dataset.
The selected tracks have strong tidal response and low residual
bias/RMS under the current thresholds.
Independent Fresnel/topobathy water-footprint validation is still
required before declaring the selected tracks confirmed open-water
reflectors or treating this as a final operational product.

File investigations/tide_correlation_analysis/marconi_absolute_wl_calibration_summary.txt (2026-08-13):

MARCONI ABSOLUTE GNSS-R WATER-LEVEL CALIBRATION
================================================================================================
H_ortho = 18.665 m
Primary calibration track: PRN 26 / GPS L1
Calibration form: GNSS_WL = TIDE + C

PRIMARY CALIBRATION CONSTANTS
------------------------------------------------------------------------------------------------
EOT20_heightm      C = -0.031938 m
GOT5.5_heightm     C = -0.066165 m
GOT5.6_heightm     C = -0.022683 m
FES2022_heightm    C = -0.022959 m
TIDE_ENSEMBLE_m    C = -0.035936 m

TRACK RESULTS — ENSEMBLE TIDE
------------------------------------------------------------------------------------------------
PRN26_AZ91_PRIMARY             N= 4 r=+0.99655 slope=+0.94003 raw_bias=-0.0359 m cal_RMS=4.18 cm cal_MAE=3.49 cm
PRN21_AZ93_VALIDATION          N= 4 r=+0.99731 slope=+1.22926 raw_bias=-0.1065 m cal_RMS=10.16 cm cal_MAE=7.16 cm
PRN16_AZ96_VALIDATION          N= 4 r=+0.99516 slope=+1.42637 raw_bias=-0.0827 m cal_RMS=12.39 cm cal_MAE=10.58 cm

PER-MODEL FIXED-CALIBRATION RESULTS
------------------------------------------------------------------------------------------------
PRN26_AZ91_PRIMARY             EOT20_heightm      r=+0.99689 slope=+0.98827 C=-0.0319 m RMS=3.19 cm MAE=3.17 cm
PRN26_AZ91_PRIMARY             GOT5.5_heightm     r=+0.99714 slope=+0.90439 C=-0.0662 m RMS=5.19 cm MAE=4.22 cm
PRN26_AZ91_PRIMARY             GOT5.6_heightm     r=+0.99598 slope=+0.94328 C=-0.0227 m RMS=4.31 cm MAE=3.75 cm
PRN26_AZ91_PRIMARY             FES2022_heightm    r=+0.99612 slope=+0.92797 C=-0.0230 m RMS=4.69 cm MAE=3.74 cm
PRN21_AZ93_VALIDATION          EOT20_heightm      r=+0.99713 slope=+1.31169 C=-0.0319 m RMS=10.85 cm MAE=8.31 cm
PRN21_AZ93_VALIDATION          GOT5.5_heightm     r=+0.99843 slope=+1.12660 C=-0.0662 m RMS=8.13 cm MAE=6.72 cm
PRN21_AZ93_VALIDATION          GOT5.6_heightm     r=+0.99654 slope=+1.25834 C=-0.0227 m RMS=11.25 cm MAE=7.95 cm
PRN21_AZ93_VALIDATION          FES2022_heightm    r=+0.99674 slope=+1.23498 C=-0.0230 m RMS=10.80 cm MAE=7.74 cm
PRN16_AZ96_VALIDATION          EOT20_heightm      r=+0.99648 slope=+1.52187 C=-0.0319 m RMS=14.10 cm MAE=12.41 cm
PRN16_AZ96_VALIDATION          GOT5.5_heightm     r=+0.99623 slope=+1.32605 C=-0.0662 m RMS=9.60 cm MAE=7.46 cm
PRN16_AZ96_VALIDATION          GOT5.6_heightm     r=+0.99356 slope=+1.45189 C=-0.0227 m RMS=13.57 cm MAE=11.61 cm
PRN16_AZ96_VALIDATION          FES2022_heightm    r=+0.99381 slope=+1.41815 C=-0.0230 m RMS=12.76 cm MAE=10.84 cm

INTERPRETATION
The calibration constant is estimated ONLY from PRN 26.
The same constant is then applied unchanged to PRN 21 and PRN 16.
This prevents the calibration from being tuned separately to
each track.

The strongest result would be a near-zero calibrated bias and
small calibrated RMS on PRN 21 and PRN 16 without refitting.

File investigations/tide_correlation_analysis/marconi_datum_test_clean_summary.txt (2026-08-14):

MARCONI DATUM TEST -- CLEAN VERSION
============================================================================================
EOT20 model: EOT20_heightm
H_ortho: 18.665 m
Independent shift: +0.242 m

POPULATION
--------------------------------------------------------------------------------------------
Raw mean: -0.2045 m
Raw median: -0.2224 m
Raw RMS: 0.4048 m
Raw MAE: 0.3018 m
Corrected mean: +0.0375 m
Corrected median: +0.0196 m
Corrected RMS: 0.3514 m
Corrected MAE: 0.2375 m
Correlation: +0.8686
Slope: +0.8865

TRACKS
--------------------------------------------------------------------------------------------
PRN  2 SETTING Az=52.89 N=17 raw_med=-0.3942 corr_med=-0.1522 raw_RMS=0.3756 corr_RMS=0.2788
PRN 20 SETTING Az=69.88 N=20 raw_med=-0.3618 corr_med=-0.1198 raw_RMS=0.4051 corr_RMS=0.2602
PRN  8 SETTING Az=83.44 N=17 raw_med=-0.3431 corr_med=-0.1011 raw_RMS=0.3989 corr_RMS=0.2618
PRN 30 RISING  Az=102.97 N=18 raw_med=-0.3247 corr_med=-0.0827 raw_RMS=0.3468 corr_RMS=0.2130
PRN 15 SETTING Az=93.26 N=22 raw_med=-0.3173 corr_med=-0.0753 raw_RMS=0.4203 corr_RMS=0.3203
PRN  5 SETTING Az=117.33 N=17 raw_med=-0.3170 corr_med=-0.0750 raw_RMS=0.3703 corr_RMS=0.2422
PRN 27 SETTING Az=63.43 N=15 raw_med=-0.3095 corr_med=-0.0675 raw_RMS=0.3636 corr_RMS=0.2265
PRN 24 SETTING Az=57.25 N=23 raw_med=-0.2957 corr_med=-0.0537 raw_RMS=0.3475 corr_RMS=0.2570
PRN  6 SETTING Az=114.73 N=18 raw_med=-0.2855 corr_med=-0.0435 raw_RMS=0.3997 corr_RMS=0.2607
PRN 12 RISING  Az=133.25 N=4 raw_med=-0.2743 corr_med=-0.0323 raw_RMS=0.2777 corr_RMS=0.0643
PRN 29 RISING  Az=113.01 N=23 raw_med=-0.2738 corr_med=-0.0318 raw_RMS=0.3095 corr_RMS=0.1650
PRN  1 SETTING Az=56.24 N=17 raw_med=-0.2689 corr_med=-0.0269 raw_RMS=0.3725 corr_RMS=0.2897
PRN 16 SETTING Az=96.48 N=15 raw_med=-0.2555 corr_med=-0.0135 raw_RMS=0.3938 corr_RMS=0.2722
PRN 21 SETTING Az=92.84 N=19 raw_med=-0.2436 corr_med=-0.0016 raw_RMS=0.4142 corr_RMS=0.2689
PRN  4 RISING  Az=96.33 N=17 raw_med=-0.2404 corr_med=+0.0016 raw_RMS=0.3151 corr_RMS=0.1967
PRN  9 RISING  Az=124.46 N=17 raw_med=-0.2215 corr_med=+0.0205 raw_RMS=0.2622 corr_RMS=0.1369
PRN 31 SETTING Az=127.05 N=8 raw_med=-0.2165 corr_med=+0.0255 raw_RMS=0.3551 corr_RMS=0.2129
PRN 13 SETTING Az=38.84 N=12 raw_med=-0.2023 corr_med=+0.0397 raw_RMS=0.2539 corr_RMS=0.1947
PRN 30 SETTING Az=33.75 N=17 raw_med=-0.1947 corr_med=+0.0473 raw_RMS=0.3815 corr_RMS=0.2546
PRN  9 SETTING Az=35.02 N=17 raw_med=-0.1798 corr_med=+0.0622 raw_RMS=0.2642 corr_RMS=0.1586
PRN  3 SETTING Az=37.18 N=16 raw_med=-0.1725 corr_med=+0.0695 raw_RMS=0.2663 corr_RMS=0.2264
PRN  4 SETTING Az=30.52 N=15 raw_med=-0.1610 corr_med=+0.0810 raw_RMS=0.2818 corr_RMS=0.1865
PRN 26 SETTING Az=90.71 N=14 raw_med=-0.1517 corr_med=+0.0903 raw_RMS=0.3629 corr_RMS=0.2624
PRN 29 SETTING Az=33.33 N=13 raw_med=-0.1405 corr_med=+0.1015 raw_RMS=0.2662 corr_RMS=0.2056
PRN 25 SETTING Az=47.61 N=16 raw_med=-0.1268 corr_med=+0.1152 raw_RMS=0.2801 corr_RMS=0.1876
PRN 12 SETTING Az=37.54 N=21 raw_med=-0.1212 corr_med=+0.1208 raw_RMS=0.2626 corr_RMS=0.2174
PRN 28 SETTING Az=114.24 N=15 raw_med=-0.1144 corr_med=+0.1276 raw_RMS=0.3113 corr_RMS=0.2259
PRN 19 SETTING Az=148.97 N=12 raw_med=+1.3494 corr_med=+1.5914 raw_RMS=1.3662 corr_RMS=1.5862

INTERPRETATION
--------------------------------------------------------------------------------------------
The +0.242 m value is an external hypothesis test.
It is not fitted to these GNSS-R observations.
A constant vertical shift changes the offset metrics but not
correlation or regression slope.

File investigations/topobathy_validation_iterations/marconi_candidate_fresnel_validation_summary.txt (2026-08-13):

MARCONI CANDIDATE FRESNEL / SHORELINE VALIDATION
==========================================================================================

IMPORTANT: water fraction is computed against the
repository-confirmed 83.06° / 71.78 m shoreline
half-plane, not a digitized shoreline polygon.

TRACK SUMMARY
------------------------------------------------------------------------------------------
PRN26_AZ91 EL=5° N=4 water_fraction_mean=1.000 min=1.000 max=1.000 center_signed_mean=+158.45 m
PRN26_AZ91 EL=9° N=4 water_fraction_mean=1.000 min=1.000 max=1.000 center_signed_mean=+51.96 m
PRN26_AZ91 EL=13° N=4 water_fraction_mean=0.880 min=0.820 max=0.936 center_signed_mean=+12.18 m
PRN21_AZ93 EL=5° N=4 water_fraction_mean=1.000 min=1.000 max=1.000 center_signed_mean=+158.60 m
PRN21_AZ93 EL=9° N=4 water_fraction_mean=1.000 min=1.000 max=1.000 center_signed_mean=+52.07 m
PRN21_AZ93 EL=13° N=4 water_fraction_mean=0.883 min=0.828 max=0.932 center_signed_mean=+12.26 m
PRN16_AZ96 EL=5° N=4 water_fraction_mean=1.000 min=1.000 max=1.000 center_signed_mean=+158.79 m
PRN16_AZ96 EL=9° N=4 water_fraction_mean=1.000 min=1.000 max=1.000 center_signed_mean=+52.21 m
PRN16_AZ96 EL=13° N=4 water_fraction_mean=0.888 min=0.825 max=0.931 center_signed_mean=+12.37 m

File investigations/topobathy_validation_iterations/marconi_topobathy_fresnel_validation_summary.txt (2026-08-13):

MARCONI TRUE TOPOBATHY / FRESNEL / TIDE VALIDATION
============================================================================================
Topobathy file: 2021022FA_Marconi_topobathy_1m.tif
DATUM_SHIFT_M: +0.000 m

ENSEMBLE-MEAN TIDE RESULTS
--------------------------------------------------------------------------------------------
PRN26_AZ91       EL=   5° N= 4 wet_mean=1.000 wet_min=1.000 wet_max=1.000 near_mean=0.000 dry_mean=0.000
PRN26_AZ91       EL=   9° N= 4 wet_mean=1.000 wet_min=1.000 wet_max=1.000 near_mean=0.000 dry_mean=0.000
PRN26_AZ91       EL=  13° N= 4 wet_mean=0.750 wet_min=0.608 wet_max=0.899 near_mean=0.052 dry_mean=0.198
PRN21_AZ93       EL=   5° N= 4 wet_mean=0.998 wet_min=0.992 wet_max=1.000 near_mean=0.000 dry_mean=0.000
PRN21_AZ93       EL=   9° N= 4 wet_mean=1.000 wet_min=1.000 wet_max=1.000 near_mean=0.000 dry_mean=0.000
PRN21_AZ93       EL=  13° N= 4 wet_mean=0.717 wet_min=0.620 wet_max=0.836 near_mean=0.060 dry_mean=0.223
PRN16_AZ96       EL=   5° N= 4 wet_mean=0.529 wet_min=0.490 wet_max=0.580 near_mean=0.000 dry_mean=0.000
PRN16_AZ96       EL=   9° N= 4 wet_mean=1.000 wet_min=1.000 wet_max=1.000 near_mean=0.000 dry_mean=0.000
PRN16_AZ96       EL=  13° N= 4 wet_mean=0.602 wet_min=0.552 wet_max=0.705 near_mean=0.056 dry_mean=0.342

INTERPRETATION
This is a baseline test using the 2021 USGS topobathy surface.
A high wet fraction means the Fresnel footprint lies mostly
below the modeled water surface elevation in the raster.
A high near-water fraction indicates intertidal/waterline
sensitivity and should not be called open ocean automatically.
A datum mismatch must be resolved before treating absolute
wet/dry classification as final.

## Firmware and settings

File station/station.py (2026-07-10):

#!/usr/bin/env python3
"""
station.py

USGS GNSS Reference Station
Version 2.0

The station controller. This module is the conductor, not one of
the musicians: it starts the application, loads configuration,
connects the receiver/database, updates station status, displays a
dashboard, handles failures gracefully, and shuts down cleanly.

It deliberately contains very little business logic. In particular,
this file never:

    * runs a SQL query           (that's database.py)
    * sends a serial command      (that's receiver.py)
    * parses RINEX                (that's rinex_processor.py)
    * runs a GNSS-IR algorithm     (that's gnssrefl_processor.py)
    * parses a file format         (that belongs in its own module)

Program flow
------------
    main()
      -> configure logging
      -> load configuration            (Config)
      -> verify configuration          (fail fast if invalid)
      -> connect database               (Database)
      -> verify database                (integrity_check)
      -> connect receiver                (Receiver, as a context manager)
      -> read receiver                    (version, position)
      -> save receiver information         (db.save_receiver_version)
      -> save position                      (db.save_position)
      -> update station status               (db.save_receiver_status)
      -> display dashboard
      -> close receiver                       (automatic: `with` block)
      -> close database                        (finally:)
      -> exit

Exit codes
----------
    0   success
    1   configuration error
    2   receiver error
    3   database error
"""

from __future__ import annotations

import logging
import os
import platform
import shutil
import sys
import time
import traceback
from datetime import datetime, timezone
from pathlib import Path

from config import Config
from database import Database, DatabaseError, DatabaseStatistics, CURRENT_SCHEMA_VERSION
from exceptions import ConfigurationError
from receiver import (
    Receiver,
    ReceiverError,
    VersionInfo,
    PositionInfo,
    CommandStats,
    API_VERSION as RECEIVER_API_VERSION,
)
from version import __version__

# Only the version constant is imported from pipeline.py -- station.py
# does not construct or run a Pipeline; that stays a separate concern
# (triggered by station_manager.py or a scheduled job), not something
# this dashboard drives. Everything else shown in the "Pipeline"
# section below is read from the database directly, so it reflects
# reality across process boundaries rather than this process's own
# (nonexistent) Pipeline state.
from pipeline import PIPELINE_VERSION

# ----------------------------------------------------------------
# Constants
# ----------------------------------------------------------------

APPLICATION_NAME = "USGS GNSS Reference Station"

EXIT_SUCCESS = 0
EXIT_CONFIG_ERROR = 1
EXIT_RECEIVER_ERROR = 2
EXIT_DATABASE_ERROR = 3

_BAR = "=" * 58

_START_TIME = time.monotonic()

_logger = logging.getLogger("station.controller")


# ----------------------------------------------------------------
# Logging
# ----------------------------------------------------------------

def configure_logging(cfg: Config) -> logging.Logger:
    """
    Configure the "station" logger (parent of "station.controller",
    "station.receiver", and "station.database") with a console
    handler and a file handler writing to logs/station.log.

    database.py additionally attaches its own dedicated handler to
    logs/database.log; because loggers propagate to their parents by
    default, database errors show up in *both* files, which is
    intentional -- one dedicated log per module, plus one combined
    log for the whole station.
    """

    logger = logging.getLogger("station")
    logger.setLevel(logging.INFO)

    if logger.handlers:
        # Already configured (e.g. called twice in one process);
        # don't stack duplicate handlers.
        return logger

    formatter = logging.Formatter(
        "%(asctime)s %(levelname)s %(name)s: %(message)s"
    )

    console_handler = logging.StreamHandler()
    console_handler.setFormatter(formatter)
    logger.addHandler(console_handler)

    log_path = cfg.logs_dir / "station.log"
    file_handler = logging.FileHandler(str(log_path))
    file_handler.setFormatter(formatter)
    logger.addHandler(file_handler)

    return logger


# ----------------------------------------------------------------
# Configuration verification
# ----------------------------------------------------------------

def verify_configuration(cfg: Config) -> None:
    """
    Sanity-check the already-loaded configuration.

    Config() itself raises FileNotFoundError/json.JSONDecodeError for
    a missing or malformed station.json, and already creates every
    required directory in its own constructor. This is a defensive
    second check -- that the values which *did* load are actually
    usable, and that the directories it created still exist -- so a
    bad station.json (e.g. an empty station_id) or a permissions
    problem is caught here, immediately, rather than surfacing later
    as a confusing failure deep in receiver.py or database.py.

    Raises
    ------
    ConfigurationError
        Listing every problem found, if any.
    """

    problems = []

    if not cfg.station_id:
        problems.append("station_id is empty")

    if not cfg.receiver_port:
        problems.append("receiver_port is empty")

    if not isinstance(cfg.receiver_baud, int) or cfg.receiver_baud <= 0:
        problems.append(f"receiver_baud is invalid: {cfg.receiver_baud!r}")

    required_directories = {
        "raw_dir": cfg.raw_dir,
        "rinex_dir": cfg.rinex_dir,
        "archive_dir": cfg.archive_dir,
        "products_dir": cfg.products_dir,
        "logs_dir": cfg.logs_dir,
        "database_dir": cfg.database_dir,
        "reports_dir": cfg.reports_dir,
        "scripts_dir": cfg.scripts_dir,
    }

    for name, path in required_directories.items():
        if not path.is_dir():
            problems.append(f"{name} does not exist: {path}")

    if problems:
        raise ConfigurationError(
            "Invalid configuration:\n  - " + "\n  - ".join(problems)
        )


# ----------------------------------------------------------------
# Small display helpers
# ----------------------------------------------------------------

def _human_bytes(size: int | None) -> str:
    """Format a byte count as e.g. '128.3 MB'. None/negative -> 'N/A'."""

    if size is None or size < 0:
        return "N/A"

    value = float(size)
    for unit in ("B", "KB", "MB", "GB", "TB"):
        if value < 1024 or unit == "TB":
            return f"{value:.1f} {unit}" if unit != "B" else f"{int(value)} {unit}"
        value /= 1024

    return f"{value:.1f} PB"  # pragma: no cover (unreachable in practice)


def _human_duration(seconds: float) -> str:
    """Format a duration in seconds as 'HH:MM:SS'."""

    seconds = int(seconds)
    hours, remainder = divmod(seconds, 3600)
    minutes, secs = divmod(remainder, 60)
    return f"{hours:02d}:{minutes:02d}:{secs:02d}"


def _read_cpu_load() -> str:
    """
    Best-effort 1-minute load average, Linux only. Returns "N/A" on
    any other platform or if it can't be read -- this is explicitly
    a "can be added properly later" field, not a hard requirement.
    """

    try:
        return f"{os.getloadavg()[0]:.2f}"
    except (OSError, AttributeError):
        return "N/A"


def _read_memory_percent() -> str:
    """
    Best-effort memory-used percentage, Linux only (reads
    /proc/meminfo directly, no extra dependency). Returns "N/A"
    anywhere that file doesn't exist or isn't parseable.
    """

    try:
        fields = {}
        with open("/proc/meminfo") as handle:
            for line in handle:
                key, _, rest = line.partition(":")
                fields[key.strip()] = int(rest.strip().split()[0])

        total = fields.get("MemTotal")
        available = fields.get("MemAvailable")

        if not total:
            return "N/A"

        used_percent = 100.0 * (total - available) / total
        return f"{used_percent:.1f}%"
    except (OSError, KeyError, ValueError, IndexError):
        return "N/A"


def _print_section(title: str) -> None:
    print()
    print(title)


def _print_field(label: str, value) -> None:
    print(f"    {label:<24}: {value}")


# ----------------------------------------------------------------
# Dashboard
# ----------------------------------------------------------------

def display_dashboard(
    cfg: Config,
    db: Database,
    rx: Receiver,
    version: VersionInfo,
    position: PositionInfo,
    stats: dict[str, CommandStats],
) -> None:
    """
    Render the full startup dashboard to stdout. Every value shown
    here was already gathered by main() via the public receiver.py /
    database.py APIs (or plain os/platform/shutil calls for system
    info); this function only formats and prints.
    """

    startup_elapsed = time.monotonic() - _START_TIME

    print(_BAR)
    print(APPLICATION_NAME)
    print()
    print(f"Version {__version__}")
    print(_BAR)
    print(f"Application Version : {__version__}")
    print(f"Database Schema      : {CURRENT_SCHEMA_VERSION}")
    print(f"Receiver API         : {RECEIVER_API_VERSION}")
    print(f"Pipeline             : {PIPELINE_VERSION}")
    print(_BAR)

    db_stats = db.database_statistics()
    station_stats = db.station_statistics()
    queue_stats = db.processing_statistics()
    today = datetime.now(timezone.utc).date().isoformat()
    today_summary = db.daily_statistics(today)

    _print_section("Station")
    _print_field("ID", station_stats.station_id)
    _print_field("Name", station_stats.station_name)

    _print_section("Receiver")
    _print_field("Model", version.model)
    _print_field("Firmware", version.firmware)
    _print_field("Hardware", version.hardware)
    _print_field("Serial Number", version.psn)
    _print_field("Compile Date", version.compile_date)

    _print_section("GNSS")
    _print_field("Solution", position.solution)
    _print_field("Latitude", f"{position.latitude:.10f}")
    _print_field("Longitude", f"{position.longitude:.10f}")
    _print_field("Height", f"{position.height:.3f} m")
    _print_field("Undulation", f"{position.undulation:.3f} m")
    _print_field("Datum", position.datum)
    _print_field("Tracked Satellites", position.num_svs_tracked)
    _print_field("Satellites in Solution", position.num_svs_in_solution)
    _print_field("Differential Age", f"{position.differential_age:.1f} s")
    _print_field("Solution Age", f"{position.solution_age:.1f} s")

    _print_section("Accuracy")
    _print_field("Latitude Std Dev", f"{position.latitude_stdev:.4f} m")
    _print_field("Longitude Std Dev", f"{position.longitude_stdev:.4f} m")
    _print_field("Height Std Dev", f"{position.height_stdev:.4f} m")

    # Merged "Database" + "Database Statistics" into one section.
    _print_section("Database")
    _print_field("Connected", db.is_connected())
    _print_field("Schema", db_stats.schema_version)
    _print_field("Tables", db_stats.total_tables)
    _print_field("Records", db_stats.total_records)
    _print_field("Size", _human_bytes(db_stats.size_bytes))
    _print_field("Last Backup", db_stats.last_backup or "None yet")

    _print_section("Files")
    _print_field("Raw Directory", cfg.raw_dir)
    _print_field("RINEX Directory", cfg.rinex_dir)
    _print_field("Product Directory", cfg.products_dir)

    newest_raw = db.latest_raw_file()
    newest_rinex = db.latest_rinex()
    newest_products = db.gnssir_history(limit=1)

    _print_section("Newest Files")
    _print_field("Raw", newest_raw.filename if newest_raw else "None yet")
    _print_field(
        "RINEX", newest_rinex.observation_file if newest_rinex else "None yet"
    )
    _print_field(
        "Product",
        newest_products[0].output_directory if newest_products else "None yet",
    )

    # New: lets the operator see at a glance whether the processing
    # pipeline is idle, has work queued, or appears to be mid-run
    # (a "RUNNING" row left over from an interrupted process counts
    # as running here too -- that's a legitimate thing to want to
    # know about). All of this is read straight from processing_queue
    # via the database, not from a live Pipeline object, since
    # whatever last touched the queue was very likely a different
    # process than this one.
    if queue_stats.running > 0:
        pipeline_status = "RUNNING"
    elif queue_stats.waiting > 0:
        pipeline_status = "WORK QUEUED"
    else:
        pipeline_status = "IDLE"

    _print_section("Pipeline")
    _print_field("Status", pipeline_status)
    _print_field("Queue Length", queue_stats.waiting + queue_stats.running)
    _print_field("Last Run", queue_stats.last_attempt or "Never")
    _print_field("Last Successful Run", queue_stats.last_successful_attempt or "Never")
    _print_field("Files Waiting", queue_stats.waiting)
    _print_field("Files Failed", queue_stats.failed)

    _print_section("Runtime Statistics")
    best_pos_stats = stats.get("BESTPOSA")
    total_queries = sum(entry.count for entry in stats.values())
    total_time = sum(entry.total_time for entry in stats.values())
    total_retries = sum(entry.failures for entry in stats.values())
    overall_average = total_time / total_queries if total_queries else 0.0
    _print_field(
        "Receiver Query Time",
        f"{best_pos_stats.average_time * 1000:.1f} ms" if best_pos_stats else "N/A",
    )
    _print_field("Average Response Time", f"{overall_average * 1000:.1f} ms")
    _print_field("Retry Count", total_retries)

    _print_section("Health")
    _print_field("Receiver Connected", rx.is_connected())
    _print_field("Database Connected", db.is_connected())
    disk_usage = shutil.disk_usage(str(cfg.project_root))
    _print_field("Disk Free", _human_bytes(disk_usage.free))
    _print_field("CPU (1m load avg)", _read_cpu_load())
    _print_field("Memory Used", _read_memory_percent())

    # New: a complete operational overview near the bottom, per file
    # type and per pipeline table, distinct from "Pipeline" above
    # (which is about queue/retry mechanics) -- this is about
    # totals. "Completed Today"/"Failed Today" come from
    # daily_summary, which pipeline.py regenerates via
    # db.generate_daily_summary() at the end of every run(); if the
    # pipeline hasn't run yet today, both read as 0 rather than
    # failing. "Failed Today" is every error logged today
    # (error_log has no per-error "was this a processing failure"
    # flag to filter on more narrowly than that).
    _print_section("Processing")
    _print_field("Raw Files", station_stats.total_raw_files)
    _print_field("RINEX Files", station_stats.total_rinex_files)
    _print_field("Products", station_stats.total_gnssir_products)
    _print_field("Pending", station_stats.pending_files)
    _print_field(
        "Completed Today", today_summary.files_processed if today_summary else 0
    )
    _print_field("Failed Today", today_summary.errors if today_summary else 0)

    _print_section("System")
    _print_field(
        "Current Time (UTC)",
        datetime.now(timezone.utc).strftime("%Y-%m-%d %H:%M:%S"),
    )
    _print_field("Uptime", _human_duration(startup_elapsed))
    _print_field("Python Version", platform.python_version())
    _print_field("Operating System", platform.platform())

    print()
    print("Status")
    print("    READY")
    print()
    print(f"    Startup Time            : {startup_elapsed:.2f} sec")
    print(_BAR)


# ----------------------------------------------------------------
# Future hooks
#
# Each of these is a placeholder for work that belongs in its own
# module (or, eventually, pipeline.py orchestrating several of
# them). Creating the functions now, even empty, gives the
# application a stable structure to grow into without station.py
# accumulating business logic of its own later.
# ----------------------------------------------------------------

def process_raw_files(cfg: Config, db: Database) -> None:
    """Placeholder: find and register newly-captured raw files."""
    pass


def convert_rinex(cfg: Config, db: Database) -> None:
    """Placeholder: convert pending raw files to RINEX (rinex_processor.py)."""
    pass


def run_gnssrefl(cfg: Config, db: Database) -> None:
    """Placeholder: run gnssrefl against converted RINEX (gnssrefl_processor.py)."""
    pass


def archive_old_files(cfg: Config, db: Database) -> None:
    """Placeholder: archive/prune old raw and RINEX files."""
    pass


def daily_maintenance(cfg: Config, db: Database) -> None:
    """Placeholder: nightly housekeeping (generate_daily_summary, backups, vacuum)."""
    pass


def health_check(cfg: Config, db: Database) -> None:
    """
    Placeholder: an automated, periodic watchdog -- distinct from
    display_dashboard()'s one-time startup snapshot -- that would
    monitor health continuously and log/alert on problems.
    """
    pass


# ----------------------------------------------------------------
# main
# ----------------------------------------------------------------

def main() -> int:
    """
    Run the station controller once: start up, read the receiver,
    record what it saw, show the dashboard, and shut down cleanly.

    Returns an exit code (see the module docstring); never raises --
    every exception is caught, logged as "Application Error", and
    translated into the appropriate code.
    """

    db: Database | None = None
    exit_code = EXIT_SUCCESS

    try:
        # ------------------------------------------------
        # Configuration
        # ------------------------------------------------

        try:
            cfg = Config()
            verify_configuration(cfg)
        except (ConfigurationError, FileNotFoundError, ValueError) as exc:
            # No logger is configured yet (it needs cfg.logs_dir), so
            # this one failure mode is reported straight to stderr.
            print(f"Configuration error: {exc}", file=sys.stderr)
            return EXIT_CONFIG_ERROR

        logger = configure_logging(cfg)
        logger.info("Application Started")

        # ------------------------------------------------
        # Database
        # ------------------------------------------------

        try:
            db = Database.from_config(cfg)
            db.connect()

            if not db.integrity_check():
                raise DatabaseError(
                    "Database failed integrity_check() after connect()"
                )
        except DatabaseError as exc:
            logger.error("Application Error: %s", exc, exc_info=True)
            return EXIT_DATABASE_ERROR

        db.save_station_info(
            station_id=cfg.station_id,
            station_name=cfg.station_name,
            organization=cfg.agency,
            latitude=cfg.latitude,
            longitude=cfg.longitude,
            height=cfg.height,
        )

        # ------------------------------------------------
        # Receiver
        # ------------------------------------------------

        try:
            with Receiver(
                device=cfg.receiver_port,
                baudrate=cfg.receiver_baud,
                timeout=cfg.receiver_timeout,
            ) as rx:

                version = rx.version()
                position = rx.best_position()

                db.save_receiver_version(version, software_version=__version__)
                db.save_position(position)

                stats = rx.stats()
                db.save_command_statistics(stats)

                best_pos_stats = stats.get("BESTPOSA")
                previous_status = db.get_receiver_status()

                db.save_receiver_status(
                    position,
                    connected=rx.is_connected(),
                    last_command="BESTPOSA",
                    last_response_time=(
                        best_pos_stats.average_time if best_pos_stats else None
                    ),
                    communication_errors=(
                        previous_status.communication_errors
                        + sum(entry.failures for entry in stats.values())
                    ),
                )

                display_dashboard(cfg, db, rx, version, position, stats)

        except ReceiverError as exc:
            logger.error("Application Error: %s", exc, exc_info=True)
            db.log_error(
                "receiver", "ERROR", exception=type(exc).__name__,
                description=str(exc), stack_trace=traceback.format_exc(),
            )
            return EXIT_RECEIVER_ERROR

        except DatabaseError as exc:
            logger.error("Application Error: %s", exc, exc_info=True)
            return EXIT_DATABASE_ERROR

        return EXIT_SUCCESS

    except Exception as exc:  # noqa: BLE001 -- last-resort safety net
        logging.getLogger("station").error(
            "Application Error: %s", exc, exc_info=True
        )
        if db is not None:
            try:
                db.log_error(
                    "station", "CRITICAL", exception=type(exc).__name__,
                    description=str(exc), stack_trace=traceback.format_exc(),
                )
            except DatabaseError:
                pass  # the database itself may be the problem; don't mask it
        exit_code = EXIT_DATABASE_ERROR if db is not None else EXIT_CONFIG_ERROR
        return exit_code

    finally:
        if db is not None:
            db.close()
        logging.getLogger("station").info("Application Stopped")


if __name__ == "__main__":
    sys.exit(main())

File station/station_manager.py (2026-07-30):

"""
station_manager.py

USGS GNSS Reference Station
Prototype 1.0

The top-level orchestrator for continuous, unattended station
operation. Turns the individually-tested modules already built
(receiver.py, database.py, pipeline.py, rinex_processor.py,
gnssrefl_processor.py) into an actual reference station that keeps
running on its own, day after day, without an operator watching it.

Mirrors the established pattern across this project: a class with
initialize()/run()/stop()/status()/shutdown(), duck-typed config
access, and resilient error handling -- a single failure (a bad
recording chunk, a pipeline error) is logged and the manager keeps
going, rather than crashing the whole unattended process.

Daily cycle
-----------
    StationManager.run()
        |
        v
    for each UTC day:
        |
        +-- record in chunks (default 1 hour each), appending to
        |   one growing raw file for the day, checking for a
        |   requested stop between chunks
        |
        +-- once the day rolls over (or a stop was requested),
        |   run the processing pipeline (raw -> RINEX -> GNSS-IR ->
        |   archive) over whatever's accumulated
        |
        +-- record a periodic system health snapshot
        |
        +-- repeat, unless a stop was requested

Chunked recording, not one call per day
-----------------------------------------
record_raw() has no built-in way to stop early -- only a fixed
`duration`. Calling it once for an entire day would mean a shutdown
signal (systemd stopping the service, a planned power-down) couldn't
take effect until the whole day finished. Recording in configurable
chunks (record_raw_chunk_seconds in station.json, default 3600) and
checking for a stop request *between* chunks bounds the worst-case
shutdown latency to one chunk, and means a single bad chunk (e.g. a
USB hiccup) only risks losing that chunk's data, not the whole day's.
Chunks are stitched into one growing per-day file using record_raw()'s
own `append=True` -- no manual file-concatenation logic needed.

Day boundaries are always UTC, matching RINEX/GNSS convention and how
the rest of this project already treats dates (pipeline.py's own
per-file dates are UTC-based already).

Graceful shutdown
------------------
SIGTERM and SIGINT are both caught and simply set a stop-requested
flag (checked between chunks, and between days) -- a signal handler
must stay minimal, so it does not attempt anything more complex than
that itself.

This module knows nothing about SQLite schema details, RINEX
parsing, or GNSS-IR analysis -- it only calls the already-established
public APIs of database.py, pipeline.py, and receiver.py, the same
way pipeline.py never touches rinex_processor.py's or
gnssrefl_processor.py's internals directly.
"""

from __future__ import annotations

from dataclasses import dataclass, field
from datetime import date, datetime, timedelta, timezone
from pathlib import Path
import logging
import os
import shutil
import signal
import time

from config import Config
from database import Database
from pipeline import Pipeline, PipelineSummary
from receiver import Receiver, ReceiverError


# ----------------------------------------------------------------
# Data classes
# ----------------------------------------------------------------

@dataclass
class StationManagerStatus:
    """Returned by status(): a snapshot for dashboards/monitoring."""

    initialized: bool = False
    running: bool = False
    stop_requested: bool = False
    current_day: str = ""
    chunks_recorded_today: int = 0
    last_pipeline_summary: PipelineSummary | None = None
    last_health_check: datetime | None = None


# ----------------------------------------------------------------
# StationManager
# ----------------------------------------------------------------

@dataclass
class StationManager:
    """
    Orchestrates continuous, unattended station operation.

    Parameters
    ----------
    cfg:
        A config.Config instance. If not given, initialize() builds
        one itself.
    db:
        A database.Database instance, shared with the internal
        Pipeline. If not given, initialize() builds and connects one
        itself.
    pipeline:
        A pre-built Pipeline instance. If not given, initialize()
        builds one itself. Either way, initialize() always calls
        pipeline.initialize() on it (matching Pipeline's own
        defensive handling of an injected db that isn't yet
        connected) -- mainly useful for tests, or for sharing a
        Pipeline across other orchestration.

    Typical usage (this is also this module's own __main__ block):

        manager = StationManager()
        manager.initialize()
        manager.run()   # blocks until stopped (Ctrl+C, SIGTERM, or
                         # manager.stop() called from elsewhere)
        manager.shutdown()
    """

    cfg: Config | None = None
    db: Database | None = None
    pipeline: Pipeline | None = None

    _owns_cfg: bool = field(default=False, init=False, repr=False)
    _owns_db: bool = field(default=False, init=False, repr=False)
    _initialized: bool = field(default=False, init=False, repr=False)
    _running: bool = field(default=False, init=False, repr=False)
    _stop_requested: bool = field(default=False, init=False, repr=False)
    _pipeline: Pipeline | None = field(default=None, init=False, repr=False)
    _chunk_seconds: float = field(default=3600.0, init=False, repr=False)
    _retry_delay_seconds: float = field(default=60.0, init=False, repr=False)
    _health_check_every_seconds: float = field(
        default=3600.0, init=False, repr=False
    )
    _export_retry_window_days: int = field(default=3, init=False, repr=False)
    _external_storage_path: Path | None = field(
        default=None, init=False, repr=False
    )
    _current_day: date | None = field(default=None, init=False, repr=False)
    _chunks_recorded_today: int = field(default=0, init=False, repr=False)
    _last_summary: PipelineSummary | None = field(
        default=None, init=False, repr=False
    )
    _last_health_check: datetime | None = field(
        default=None, init=False, repr=False
    )
    _logger: logging.Logger = field(
        default_factory=lambda: logging.getLogger("station.manager"),
        init=False,
        repr=False,
    )

    # ==========================================================
    # Public API
    # ==========================================================

    def initialize(self) -> str:
        """
        Connect the database, initialize the processing pipeline,
        read configuration, and register signal handlers for
        graceful shutdown.

        Returns "READY" on success.
        """

        if self.cfg is None:
            self.cfg = Config()
            self._owns_cfg = True
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

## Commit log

2026-07-10 Add files via upload
    3d Printer step files for the Ardusimple board to protect it inside the electronics box
    [Ardusimple box.stp, ardusimple lid.stp]
2026-07-10 Create 3d printer files for ardusimple
2026-07-10 Organize 3D enclosure files into their own folder
    [Ardusimple box.stp, ardusimple lid.stp]
2026-07-15 Fix RINEX decode crash, multi-constellation processing, date-parsing bug, and add external storage export
    - rinex_processor.py: handle non-UTF-8 bytes from convbin gracefully
    instead of crashing conversion (confirmed against real overnight data)
    - gnssrefl_processor.py: enable allfreq=True by default (was silently
    GPS-only despite multi-constellation hardware); corrected orbit
    source guidance
    - pipeline.py: derive each raw file's processing date from its
    filename, not modification time (mtime drifted from repeated
    retries, causing every backlogged day to process under the wrong
    day-of-year)
    - station_manager.py: new external_storage_path export feature,
    moves each day's raw fil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
    [gnssrefl_processor.py, pipeline.py, rinex_processor.py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]
2026-07-20 Add ediff/delTmax fine-tuning, precise PPP-derived coordinates, flattened export structure, and NOAA comparison tooling
    - gnssrefl_processor.py: expose delTmax (max arc length) and ediff
    (arc elevation-span tolerance) as configurable parameters, both
    confirmed important for a narrow elevation mask on a fast-tide
    site via direct documentation research and real pipeline evidence
    - station.json: update to precise CSRS-PPP-derived coordinates and
    ellipsoidal height (real self-surveyed position, replacing an
    estimate that was off by ~31m in the ellipsoidal/orthometric
    height reference), correct antenna model, and full site-specific
    gnssrefl tuning (water-specific elevation mask, ref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
    [tides_1_2026-07.csv]
2026-07-30 Clean up backup scope: exclude all data/archives, add tonight's new GNSS scripts
    - Removed tracked data files that shouldn't have been backed up: a raw
    RINEX file, two archives (zip/tar.gz), a database log, tide reference
    CSV, and stale/empty leftover files
    - Removed stray duplicate copies of gnssrefl_processor.py,
    test_gnssrefl_processor.py, and compare_to_tide_models.py, keeping
    each file's correct, current version in its proper location
    - Updated .gitignore to reliably exclude all generated GNSS data,
    archives, reference data files, and hardware design files -- backup
    scope is now GNSS scripts, code, and documentation only
    - Added new scripts built tonight: compare_to_tide_mod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
    [Ardusimple box.stp, ardusimple lid.stp, tides_1_2026-07.csv]
2026-08-12 Fix comparison methodology, and investigate reflection zone geometry
    - analyze_gnssir_tide_relationship.py: widened the timing-lag search
    to +/-300 minutes (was +/-120, too narrow to detect a real 4-hour
    timezone offset), fixed a plotting bug drawing the reference line
    across a mismatched axis range, removed a duplicate code block
    - run_damping_correction.py: switched the tide-model comparison to a
    unit-slope fit (matching the 99-arc baseline methodology exactly),
    for a genuinely fair before/after comparison
    - Confirmed, via a corrected regex, that the production GNSS-IR log
    SUCCESS count is exactly 99 (matching the extract_arcs-based
    dataset exactly, frequency-for-frequency) -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
2026-08-12 Redesign azimuth mask around confirmed true water bearing, test and document results
    - Fixed a real bug in test_marconi_ocean_mask.py: it passed the
    orthometric height (18.665m) as the reflector-height parameter to
    makeEllipse_latlon(), producing ellipses ~11.7x too large; the
    corrected version uses our real observed RH range (0.51-2.12m)
    - Built and visually verified two candidate water-facing masks
    (100 deg centered on the confirmed true 83 deg bearing, then a wider
    180 deg version) using gnssrefl's own refl_zones geometry and direct
    measurement in Google Earth against real satellite imagery
    - Applied the 180 deg mask to production (station.json and usgs.json
    azval2, now [353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
2026-08-13 Discover and fix real NReg config bug; test widened RH search across multiple satellites
    - Major finding: gnssir's noise-floor estimation reads a SEPARATE
    'NReg' config field, independent of minH/maxH. quickLook sets
    NReg=[minH,maxH] automatically every run; gnssir does not. Our
    production NReg was still [-0.5, 5.0] even after minH/maxH were
    widened for testing, causing every arc's noise estimate to compute
    as exactly 0 (confirmed via a real, reproducible divide-by-zero at
    gps.py line 2914) and silently fail every arc in the new range.
    Traced through gps.py, quickLook_function2.py, and retrieve_rh.py
    to find and confirm the root cause before fixing it.
    - Set up an isolated oc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
2026-08-13 Add real topo-bathymetry data and terrain-based Fresnel footprint validation tools
    - Added real, 1m-resolution topo-bathymetry raster (2021022FA_Marconi_topobathy_1m.tif,
    6.3MB) as reference data underlying proper Fresnel-footprint-vs-actual-terrain
    classification, rather than relying on bearing-line/distance
    approximations alone
    - marconi_topobathy_fresnel_validation.py / .kml / summary: classifies
    candidate reflection footprints against real terrain data
    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
2026-08-13 Falsify the 17-23m 'breakthrough' correlation as a shared, azimuth-independent artifact
    - analyze_ocean17_23_tracks.py's repeated-track results initially
    looked like a major finding: many tracks (sat 26, 21, 16, 12, etc.)
    showed r~-0.99 and slope near the physically expected -1, with RMS
    as low as 3-13cm -- far better than anything else tested tonight
    - Direct test: sorted every track by azimuth and checked whether
    correlation strength actually depends on direction. It does not
    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
2026-08-14 Extended (22-day) repeated-track analysis and vertical datum correction work
    - analyze_ocean17_23_tracks_extended.py: extends the 17-23m repeated-
    track tide analysis from the original 4-day window (204-207) to the
    full 22-day available dataset (196-221, spanning ~1.5 spring-neap
    cycles). Confirmed the tide genuinely reverses direction 185 times
    over this period (no longer monotonic), so this is a real,
    decisive test of whether the strong correlation found in the 4-day
    window is genuine or a short-window coincidence
    - Result: correlation stayed strong (|r|=0.87-0.97) across nearly
    every track even against the now-oscillating tide, weakening the
    earlier 'simple monotonic coinc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
2026-08-20 Investigate the shared-artifact pattern: refraction and elevation-dependence tests, plus V2-V8 iterative pipeline development
    - Fixed a real, confirmed bug in process_all_and_plot.py's spline
    parser: it previously guessed the file format incorrectly (assumed
    column 0 was simple fractional day-of-year), producing dates off by
    ~167 years. Verified the real format directly against actual file
    contents (MJD + explicit YYYY/MM/DD/HH/MM/SS columns + a
    pre-computed quasi-sea-level column) and fixed it to match
    - rinex_inventory.py: system-wide RINEX file discovery tool, finds
    every RINEX file regardless of location, identifies genuinely
    missing days vs. days with RINEX not yet convert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
    [marconi_longterm_population_statistics_v6.csv, marconi_longterm_population_statistics_v7.csv, marconi_longterm_population_statistics_v8.csv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]
2026-08-20 Fix NReg bug, add validate_station.py, archive investigation history
    - station/gnssrefl_processor.py: fixed a real, confirmed bug in
    _setup_station_strategy() where NReg (gnssir's noise-floor
    estimation region) was never set independently of h1/h2 (the RH
    search region). gnssrefl reads these as separate config fields --
    without NReg tracking h1/h2, every arc's noise-floor sample comes
    back empty and every arc silently fails QC. This exact bug was
    independently discovered and fixed by hand earlier this session in
    isolated test configs; this closes the same gap in the real,
    production pipeline code, so widening the RH range in station.json
    in the future won't silently reprodu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
    [marconi_longterm_population_statistics_v6.csv, marconi_longterm_population_statistics_v7.csv, marconi_longterm_population_statistics_v8.csv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]
2026-08-20 Fix NReg bug correctly: use nr1/nr2, not a nonexistent NReg kwarg
    The first attempt at this fix (commit 9deb4c6c) passed NReg=[h1, h2]
    directly as a keyword argument to make_gnssir_input(), which does
    not exist as a parameter on that function -- confirmed directly via
    inspect.signature() against the real, installed gnssrefl 4.1.5:
    make_gnssir_input(station, lat=0, lon=0, height=0, e1=5.0,
    e2=25.0, h1=0.5, h2=8.0, nr1=None, nr2=None, peak2noise=2.8,
    ampl=5.0, allfreq=False, ...)
    The function takes nr1/nr2 as two separate float parameters and
    builds station_config['NReg'] = [nr1, nr2] internally -- there is no
    'NReg' keyword on the function itself. The previous fix's untested
    ass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
    [gnssrefl_processor.py]
2026-08-20 Fix staged-RINEX-file disk leak; fix pre-existing gnssrefl-importable test gap
    station/gnssrefl_processor.py:
    - Confirmed, real bug: _stage_rinex_file()'s copy into gnssrefl's
    working directory was never cleaned up after process() finished
    using it. The only existing cleanup (removing a same-named stale
    file before staging a new one) never triggers for a day processed
    exactly once, the normal case. Confirmed directly on real
    hardware: 29 accumulated files, 9.3GB, in station/ after several
    weeks of ordinary operation, with no upper bound on further
    growth -- discovered while investigating unexpectedly high disk
    usage, traced to this exact root cause.
    - process() now captures t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
    [gnssrefl_processor.py]
2026-08-20 Harden recover_missing_days.sh: survive interruption, stop lying about no-data days
    Two real bugs found by actually running this script against real
    station data, not assumed:
    1. Confirmed disk leak: the staged RINEX copy (~350-400MB per day)
    was only ever cleaned up by a plain, sequential "rm -f" line
    after processing finished -- which does not run if the script
    itself is interrupted mid-iteration (SSH disconnect, Ctrl+C, the
    process being killed). Confirmed directly: 35 files matching
    exactly this staged-copy pattern were found accumulated at the
    project root from prior runs. Fixed using bash's `trap ... EXIT`,
    which fires even under interruption, unlike a plain seque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
2026-08-21 Add master install/test/process scripts, validation tooling, and docs
    New master scripts, consolidating and hardening this project's setup
    and operation into three clear entry points, each tested against
    real hardware and real data over the course of this session:
    - install.sh: checks/installs every system dependency (Python,
    RTKLIB's convbin built from source against the current
    post-demo5-retirement upstream, gnssrefl), sets up the venv and
    directory structure, hands off to setup_station.sh. Confirmed
    non-destructive against this station's existing, live setup.
    - test_installation.sh: beginner-friendly pass/fail verification of
    the whole environment, including a new check for R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
2026-09-28 Put GNSS-IR water levels on NAVD88 and fix the antenna height never reaching gnssrefl
    Datum
    - station.json: gnssrefl_orthometric_height 18.665 -> 19.014 m (NGS OPUS,
    NAVD88/GEOID18). 18.665 came from CSRS-PPP and is CGVD2013.
    - gnssrefl_processor: pass Hortho as a list. make_gnssir_input() only
    writes Hortho to the json when it is a list and silently drops a float,
    so subdaily fell back to ellipsoid height minus EGM96 (18.625 m) and the
    configured value never reached the spline. Verified against gnssrefl
    4.1.5: [19.014] is written, 19.014 is not.
    - New station_datum.py: reads Hortho from station.json, holds the tide
    model -> NAVD88 shift (+0.09 m) and the history of both numbers.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
    [gnssrefl_processor.py]
